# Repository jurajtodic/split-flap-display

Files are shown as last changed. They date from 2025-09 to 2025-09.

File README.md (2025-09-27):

# ESP32 WiFi Controlled Split-Flap Display

This repository contains the complete technical documentation, 3D models, and firmware for a fully functional, 8-module electromechanical split-flap display. The entire system is controlled over Wi-Fi via a web interface hosted directly on the ESP32 microcontroller.

### Watch the Display in Action!

Below are silent previews of the display's two primary modes. The iconic sound is a key feature, so click the title links to see and hear the full videos.

---

### [**Word Mode Demo (Click for Video with Sound)**](https://github.com/jurajtodic/split-flap-display/raw/main/assets/word_mode_test.mp4)

*Displaying a custom message sent from the web interface. The video shows the recalibration process followed by the display of the word "HELLO WORLD".*

Demonstration of the Split-Flap Display in Word Mode

---

### [**Clock Mode Demo (Click for Video with Sound)**](https://github.com/jurajtodic/split-flap-display/raw/main/assets/clock_mode_test.mp4)

*The display functioning as an internet-synchronized clock, updating every second to show the time in HH:MM:SS format.*

Demonstration of the Split-Flap Display in Clock Mode

---

## Project Overview

Inspired by the classic departure boards found in train stations and airports, this project recreates the iconic and satisfying "clatter" of a split-flap display in a compact, modern, and open-source package. The display has a dual-mode functionality: it can operate as a web-controlled message board or as an accurate, internet-synchronized clock.

The core engineering challenge was to create a reliable and precise positioning system for eight independent stepper motors without accumulating errors over time. This was solved using a closed-loop feedback mechanism with Hall effect sensors, all managed by a non-blocking state machine architecture in the firmware.

## Key Features

*   **8 Independent Modules:** An 8-character display capable of showing the full alphabet, numbers, and symbols.
*   **Wi-Fi Control:** Features a built-in web server hosted on the ESP32, allowing you to change messages and modes from any device on the network.
*   **Dual Mode Functionality:**
    *   **Word Mode:** Display any custom message up to 8 characters long.
    *   **Clock Mode:** Automatically fetches the current time from an NTP server and displays it in HH:MM:SS format.
*   **Auto-Calibration & Error Correction:** Each module uses a magnet and a Hall effect sensor to find a "home" position, preventing cumulative errors. The firmware also features an on-the-fly error correction mechanism that passively corrects for missed steps during operation.
*   **Non-Blocking Code:** The firmware is built on a state-machine model, allowing it to manage motor movements, serve the web page, and listen for commands simultaneously without delays.
*   **Fully Open Source:** All hardware schematics, 3D printable models, and source code are available here.

## How It Works

The system is a blend of mechanical design, custom electronics, and advanced firmware.

### Mechanical Design

The display is modular, with each of the eight character units being identical. The housing, rotor, and flaps were modeled in Tinkercad and are designed to be 3D printed. Precision is key to ensure the 36 flaps on each rotor can move freely without jamming.

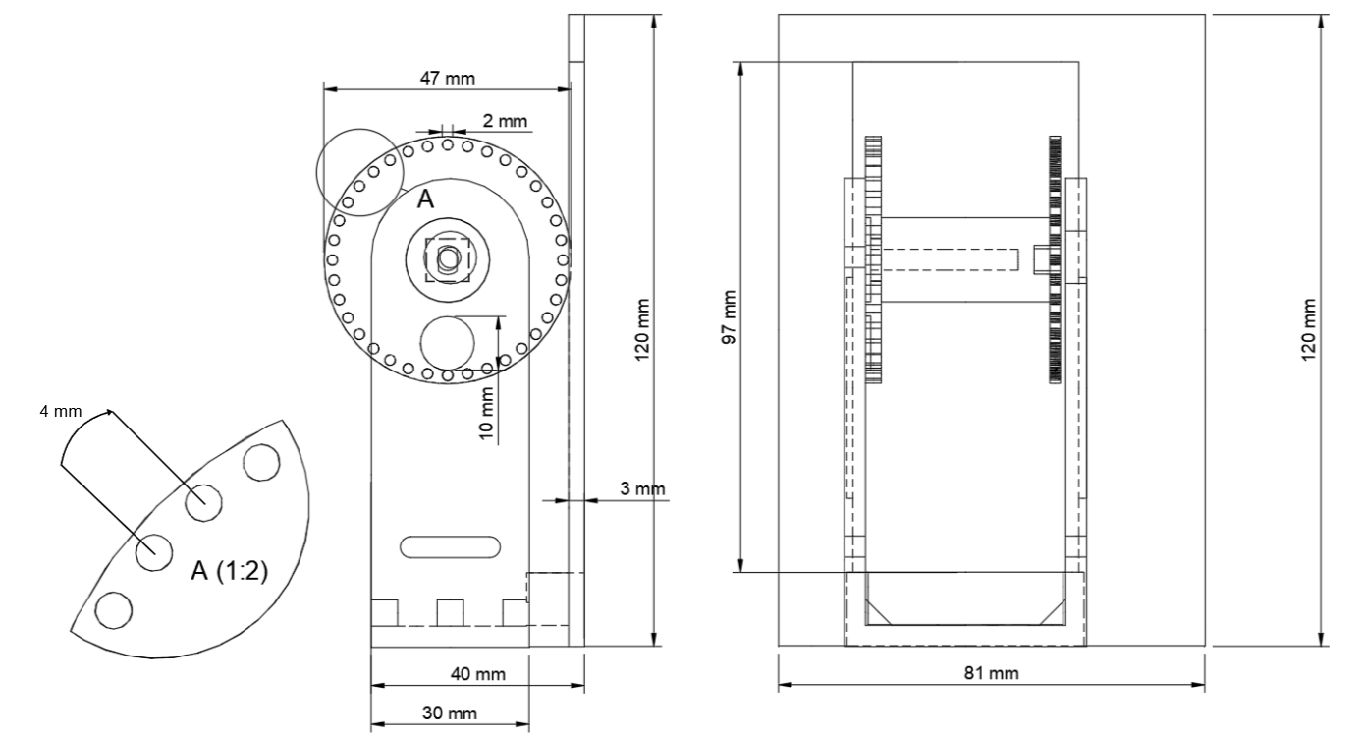
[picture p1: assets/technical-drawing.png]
Technical Drawing of a Single Module


### Electronics and Wiring

An ESP32-DevKitC serves as the brain of the project. Since the ESP32 lacks enough GPIO pins to directly control all eight stepper motors (requiring 32 lines), four **74HC595 shift registers** are used to expand the outputs. This allows all 32 motor control lines to be managed using just three ESP32 pins (DATA, CLOCK, LATCH).

Each module's feedback loop consists of a small neodymium magnet embedded in the rotor and an **A3144 Hall effect sensor** mounted to the frame. When the magnet passes the sensor, a signal is sent to the ESP32, marking a precise reference point.

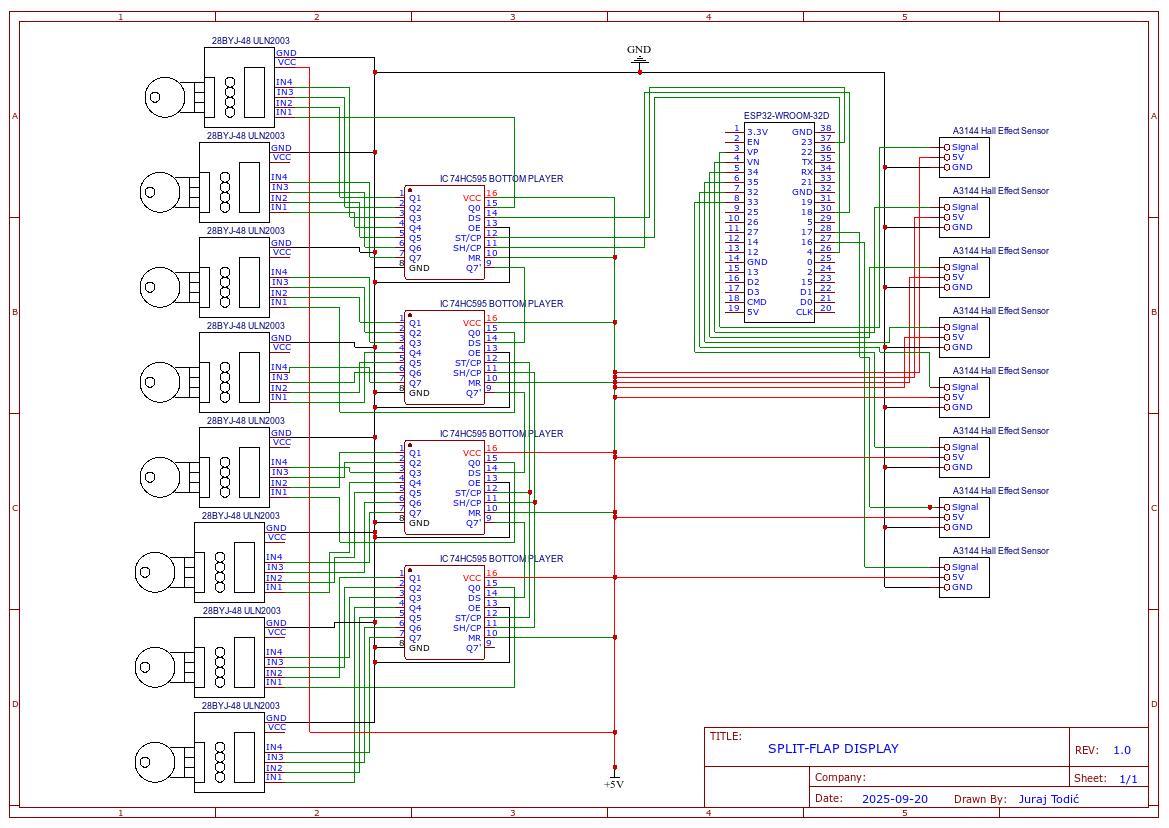
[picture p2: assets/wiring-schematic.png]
Complete Wiring Schematic


### Software Breakdown

The firmware is developed in C++ using the PlatformIO IDE. The core logic is a **non-blocking state machine**. Instead of using `delay()` functions that would halt the processor, the main `loop()` runs thousands of times per second. In each cycle, it:
1.  Checks for incoming web clients.
2.  Updates the state of each of the eight motors (e.g., `IDLE`, `MOVING_TO_TARGET`, `RECALIBRATING`).
3.  Calculates the necessary motor steps based on trapezoidal speed profiles for smooth acceleration and deceleration.
4.  Sends the updated motor states as a single 32-bit pattern to the shift registers.

This approach ensures the device is always responsive to web commands, even while the motors are in motion.

## Getting Started

To build your own split-flap display, follow these steps.

### Prerequisites

*   All the hardware components listed in the technical report.
*   A 3D printer to create the mechanical parts.
*   Visual Studio Code with the **PlatformIO IDE** extension installed.

### Setup and Upload

1.  **Clone the repository:**
    ```sh
    git clone https://github.com/your-username/your-repo-name.git
    ```
2.  **Open the project** in Visual Studio Code. It should be automatically recognized as a PlatformIO project.
3.  **Configure Wi-Fi:** Open the `src/main.cpp` file and update the following lines with your network credentials:
    ```cpp
    const char* ssid = "YOUR_WIFI_SSID";
    const char* password = "YOUR_WIFI_PASSWORD";
    ```
4.  **Build and Upload:** Connect your ESP32 board to your computer and click the "Upload" button in the PlatformIO toolbar at the bottom of VS Code.
5.  **Find the IP Address:** After uploading, open the Serial Monitor. The ESP32 will print its IP address once it connects to your network.

### How to Use

1.  Open a web browser on any device connected to the same Wi-Fi network.
2.  Navigate to the IP address you found in the previous step.
3.  Use the web interface to switch between Word and Clock mode, or to enter a new message to display!

## Known Issues & Future Improvements

This prototype is fully functional but, as a first iteration, has clear areas for enhancement to improve its long-term reliability and ease of assembly.

*   **Firmware Edge Cases:** The state-driven, non-blocking firmware is highly efficient but can occasionally exhibit unpredictable behavior in rare edge cases (e.g., a web request arriving at the exact moment a motor state changes). If a module behaves erratically or gets stuck unexpectedly, a software fix should be considered. Investigating and reinforcing the state machine logic in the firmware should be the first step in debugging.
*   **Mechanical Tolerances:** The 3D printed parts have inherent tolerances that can lead to minor misalignments, which is the primary source of occasional display errors. A design with tighter tolerances would improve performance.
*   **Sensor Placement:** The manual placement of the Hall effect sensors is critical and highly sensitive. A revised 3D model with a fixed, non-adjustable mounting point for the sensors would greatly improve reliability and simplify the calibration process.

## Inspiration and Credits

This project was heavily inspired by the work of other makers in the open-source community.

A special thanks goes to **Scott Bezek** for his incredible [splitflap project](https://github.com/scottbez1/splitflap), which served as a foundational resource.

Additionally, I would like to credit **AudasWasTaken**. The 3D models in this project were originally based on the files from their [Split-Flap_Display repository](https://github.com/AudasWasTaken/Split-Flap_Display) and were then modified to fit the specific components and mechanics of this design.

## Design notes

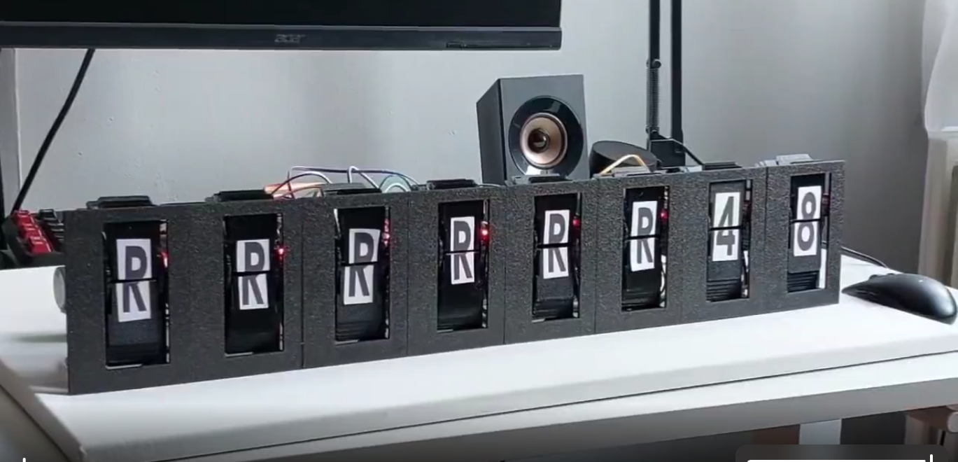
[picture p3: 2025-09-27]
assets/thumbnail.png

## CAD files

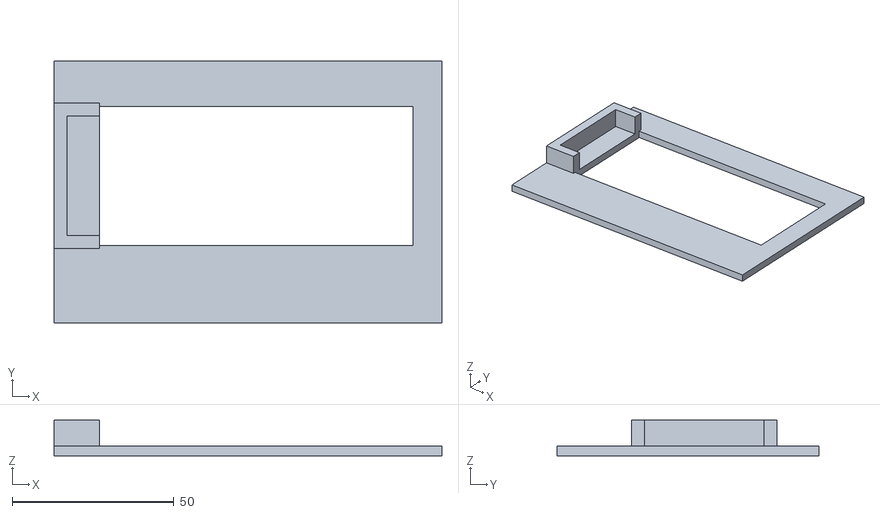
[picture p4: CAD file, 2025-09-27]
3d_model/spool_cover.stl
120.0 x 81.0 x 11.0

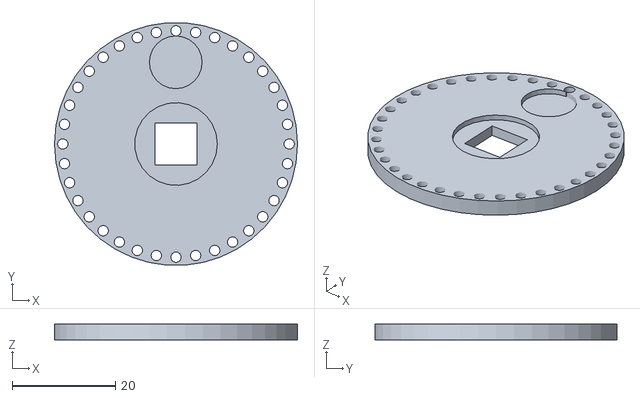
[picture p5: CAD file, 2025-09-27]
3d_model/split-flap_spool_top.stl
47.0 x 46.9 x 3.00

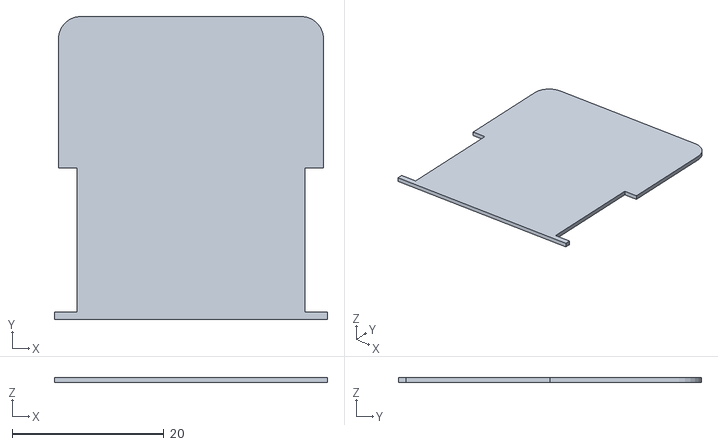
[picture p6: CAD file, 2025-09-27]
3d_model/split-flap_flap.stl
36.0 x 40.0 x 0.7

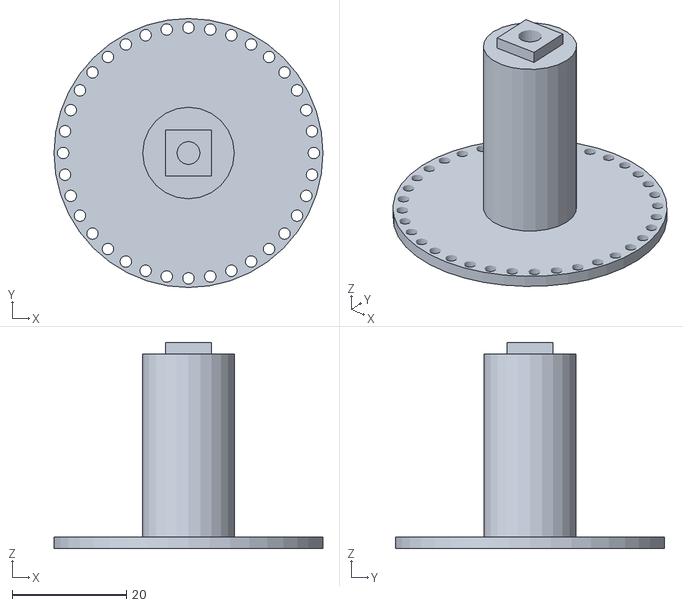
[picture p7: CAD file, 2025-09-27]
3d_model/split-flap_spool_bot.stl
47.0 x 47.0 x 36.0

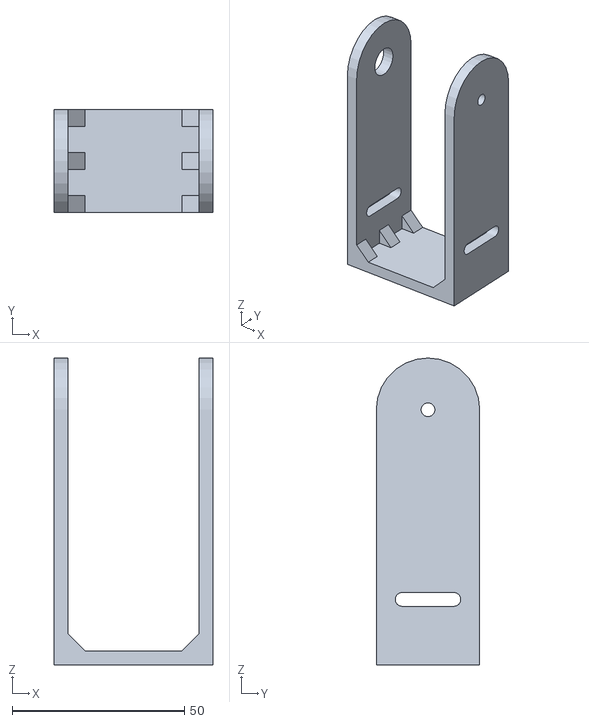
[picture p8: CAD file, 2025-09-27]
3d_model/split-flap_case.stl
46.0 x 30.0 x 89.0

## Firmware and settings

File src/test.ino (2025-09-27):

#include <Arduino.h>
#include <SPI.h>
#include <WiFi.h>
#include <NTPClient.h>
#include <WiFiUdp.h>

// --- Wi-Fi & Time Configuration ---
const char* ssid = "JurajevMob";
const char* password = "juki1234";
WiFiServer server(80);
WiFiUDP ntpUDP;
NTPClient timeClient(ntpUDP, "pool.ntp.org", 7200); 
int lastDisplayedSecond = -1;

// --- System Configuration ---
const int NUM_STEPPERS = 8;
const int NUM_SHIFT_REGISTERS = 4;
const int DATA_PIN = 23;
const int CLOCK_PIN = 18;
const int LATCH_PIN = 4;

// --- Stepper Motor & Flap Properties ---
const int STEPS_PER_REVOLUTION = 2048;
const int NUM_FLAPS = 36;
const long BASE_STEPS_PER_FLAP = STEPS_PER_REVOLUTION / NUM_FLAPS;

// --- Behavior Configuration ---
const int MOVES_FOR_RECALIBRATION_WORD_MODE = 2;
const int NUDGE_STEPS = 35;
const long RECALIBRATION_TIMEOUT_STEPS = STEPS_PER_REVOLUTION * 2;
const int BLIND_SPIN_STEPS = 300; 

// --- Speed & Ramping Configuration ---
const int MAX_SPEED_DELAY_US = 2200;
const int START_STOP_DELAY_US = 2200;
const int RECALIBRATE_DELAY_US = 2200;
const int RAMP_STEPS = 300;

// --- Character Mapping ---
const char letterMap[] = {
    'R', 'S', 'T', 'U', 'V', 'W', 'X', 'Y', 'Z', '9', '8', '7',
    '6', '5', '4', '3', '2', '1', '0', 'A', 'B', 'C', 'D', 'E',
    'F', 'G', 'H', 'I', 'J', 'K', 'L', 'M', 'N', ':', 'P', 'Q'
};
const char tensDigitMap[] = {
    '4', '5', '0', '1', '2', '3', '4', '5', '0', '1', '2', '3',
    '4', '5', '0', '1', '2', '3', '4', '5', '0', '1', '2', '3',
    '4', '5', '0', '1', '2', '3', '4', '5', '0', '1', '2', '3'
};
const char unitsDigitMap[] = {
    '8', '9', '0', '1', '2', '3', '4', '5', '6', '7',
    '8', '9', '0', '1', '2', '3', '4', '5', '6', '7',
    '8', '9', '0', '1', '2', '3', '4', '5', '6', '7',
    '8', '9', '0', '1', '2', '3'
};

// --- Low-Level Control ---
const byte step_patterns[] = {0b1001, 0b1100, 0b0110, 0b0011};
byte output_buffer[NUM_SHIFT_REGISTERS];

// --- System State Machine ---
enum DisplayMode { WORD_MODE, CLOCK_MODE };
DisplayMode currentMode = WORD_MODE;

enum MotorActivity {
    IDLE, RECALIBRATING_START, RECALIBRATING_BLIND_SPIN, RECALIBRATING_FIND_HOME, RECALIBRATING_FIND_EDGE,
    MOVING_TO_TARGET, NUDGING_FORWARD, NUDGING_BACKWARD, HALTED
};

struct MotorState {
    const int hall_pin;
    MotorActivity state = RECALIBRATING_START;
    long current_pos = 0;
    long target_pos = 0;
    int phase = 0;
    unsigned long last_step_time_us = 0;
    int current_step_delay_us = START_STOP_DELAY_US;
    long steps_in_current_move = 0;
    long total_steps_for_move = 0;
    int nudge_step_counter = 0;
    int moves_since_recalibration = 0; // Only for WORD_MODE
    char post_recal_target_char = '\0';
    long recalibration_step_counter = 0;

    // --- "LAP TIMER" VARIABLES ---
    long steps_since_last_home = 0;
    long position_error = 0;
    // This flag is our "memory" of the sensor's previous state to detect a fresh trigger.
    bool home_sensor_active = false; 

    MotorState(int pin) : hall_pin(pin) {}
};

MotorState motors[NUM_STEPPERS] = {
  {36}, {39}, {34}, {35}, {32}, {33}, {17}, {16}
};

void setTargetWord(String word);

// --- Core Functions ---
void updateShiftRegisters(bool releaseTorque) {
    if (releaseTorque) { memset(output_buffer, 0, sizeof(output_buffer)); }
    digitalWrite(LATCH_PIN, LOW);
    for (int i = NUM_SHIFT_REGISTERS - 1; i >= 0; i--) { SPI.transfer(output_buffer[i]); }
    digitalWrite(LATCH_PIN, HIGH);
}

void stepMotor(int motorIndex, bool forward) {
    motors[motorIndex].phase = (motors[motorIndex].phase + (forward ? -1 : 1) + 4) % 4;
    motors[motorIndex].current_pos += (forward ? 1 : -1);
    byte pattern = step_patterns[motors[motorIndex].phase];
    int start_bit_pos = motorIndex * 4;
    int start_byte_index = start_bit_pos / 8;
    int bit_shift_in_byte = start_bit_pos % 8;
    
    output_buffer[start_byte_index] &= ~(0b1111 << bit_shift_in_byte);
    if (bit_shift_in_byte > 4 && start_byte_index + 1 < NUM_SHIFT_REGISTERS) {
         output_buffer[start_byte_index + 1] &= ~(0b1111 >> (8-bit_shift_in_byte));
    }
    output_buffer[start_byte_index] |= (pattern << bit_shift_in_byte);
    if (bit_shift_in_byte > 4 && start_byte_index + 1 < NUM_SHIFT_REGISTERS) {
        output_buffer[start_byte_index + 1] |= (pattern >> (8 - bit_shift_in_byte));
    }

    // --- "LAP TIMER" LOGIC ---
    motors[motorIndex].steps_since_last_home++;
    
    // Check the sensor's state RIGHT NOW. (LOW means active)
    bool is_active = (digitalRead(motors[motorIndex].hall_pin) == LOW);
    
    // Check for the LEADING EDGE: Was the sensor OFF before, but is ON now?
    if (is_active && !motors[motorIndex].home_sensor_active) {
        // Lap complete! Calculate the error from the ideal revolution size.
        motors[motorIndex].position_error = motors[motorIndex].steps_since_last_home - STEPS_PER_REVOLUTION;
        Serial.printf("Motor %d: LAP! %ld steps. Error: %ld\n", motorIndex, motors[motorIndex].steps_since_last_home, motors[motorIndex].position_error);
        
        // Reset the lap counter for the next revolution.
        motors[motorIndex].steps_since_last_home = 0;
    }
    
    // Update the "memory" for the next step's comparison.
    motors[motorIndex].home_sensor_active = is_active;
}

// --- Main Action Functions ---
void setTargetWord(String word) {
    for (int i = 0; i < NUM_STEPPERS; i++) {
        if (motors[i].state == RECALIBRATING_BLIND_SPIN || motors[i].state == RECALIBRATING_FIND_HOME || motors[i].state == RECALIBRATING_FIND_EDGE) {
            continue;
        }
        if (motors[i].state == HALTED) continue;

        if (motors[i].position_error != 0) {
            motors[i].current_pos -= motors[i].position_error; // Apply correction
            Serial.printf("Motor %d: Applying correction of %ld steps.\n", i, -motors[i].position_error);
            motors[i].position_error = 0; // Clear error after use
        }

        char targetLetter = (i < word.length()) ? toupper(word[i]) : ' ';
        if (targetLetter == 'O') targetLetter = '0';

        long current_flap_pos = (motors[i].current_pos % STEPS_PER_REVOLUTION) / BASE_STEPS_PER_FLAP;
        long flaps_to_move = 0;
        int targetIndex = -1;

        if (currentMode == WORD_MODE) {
            if (i >= 6) targetLetter = ' ';

            for (int j = 0; j < NUM_FLAPS; j++) { if (letterMap[j] == targetLetter) { targetIndex = j; break; } }
            if (targetIndex == -1) continue;

            motors[i].moves_since_recalibration++;
            if (motors[i].moves_since_recalibration >= MOVES_FOR_RECALIBRATION_WORD_MODE) {
                motors[i].post_recal_target_char = targetLetter;
                motors[i].state = RECALIBRATING_START;
                continue;
            }
            flaps_to_move = (targetIndex - current_flap_pos + NUM_FLAPS) % NUM_FLAPS;
        } else { // CLOCK_MODE
            const char* currentMap;
            int numUniqueFlaps;

            if (i < 6) { currentMap = letterMap; numUniqueFlaps = NUM_FLAPS; }
            else if (i == 6) { currentMap = tensDigitMap; numUniqueFlaps = 6; }
            else { currentMap = unitsDigitMap; numUniqueFlaps = 10; }

            for (int j = 0; j < NUM_FLAPS; j++) { if (currentMap[j] == targetLetter) { targetIndex = j; break; } }
            if (targetIndex == -1) continue;
            
            if (i < 6) {
                 flaps_to_move = (targetIndex - current_flap_pos + NUM_FLAPS) % NUM_FLAPS;
            } else {
                long current_flap_unique_pos = current_flap_pos % numUniqueFlaps;
                long target_flap_unique_pos = targetIndex % numUniqueFlaps;
                flaps_to_move = (target_flap_unique_pos - current_flap_unique_pos + numUniqueFlaps) % numUniqueFlaps;

                if (flaps_to_move == 0 && i == 7) { 
                    flaps_to_move = numUniqueFlaps; 
                }
            }
        }

        if (flaps_to_move > 0) {
            long steps_to_move = flaps_to_move * BASE_STEPS_PER_FLAP;
            motors[i].target_pos = motors[i].current_pos + steps_to_move;
            motors[i].total_steps_for_move = steps_to_move;
            motors[i].steps_in_current_move = 0;
            motors[i].state = MOVING_TO_TARGET;
        } else {
            motors[i].state = IDLE;
        }
    }
}

void recalibrateAllMotors() {
    Serial.println("Web request received: Recalibrating all motors.");
    for (int i = 0; i < NUM_STEPPERS; i++) {
        if (motors[i].state != HALTED) {
            motors[i].post_recal_target_char = '\0';
            motors[i].state = RECALIBRATING_START;
        }
    }
}

// --- State Machine ---
void updateMotor(int motorIndex) {
    MotorState &motor = motors[motorIndex];
    if (motor.state == IDLE || motor.state == HALTED) { return; }
    if (micros() - motor.last_step_time_us < motor.current_step_delay_us) { return; }
    motor.last_step_time_us = micros();

    switch (motor.state) {
        case RECALIBRATING_START:
            motor.current_step_delay_us = RECALIBRATE_DELAY_US;
            motor.recalibration_step_counter = 0;
            motor.state = RECALIBRATING_BLIND_SPIN;
            break;

        case RECALIBRATING_BLIND_SPIN:
            if (motor.recalibration_step_counter >= BLIND_SPIN_STEPS) {
                motor.recalibration_step_counter = 0;
                motor.state = RECALIBRATING_FIND_HOME;
                break;
            }
            stepMotor(motorIndex, true);
            motor.recalibration_step_counter++;
            break;

        case RECALIBRATING_FIND_HOME:
            stepMotor(motorIndex, true); motor.recalibration_step_counter++;
            if (digitalRead(motor.hall_pin) == HIGH) {
                motor.state = RECALIBRATING_FIND_EDGE;
            }
            if (motor.recalibration_step_counter > RECALIBRATION_TIMEOUT_STEPS) {
                motor.state = HALTED;
            }
            break;

        case RECALIBRATING_FIND_EDGE:
            stepMotor(motorIndex, true);
            motor.recalibration_step_counter++;
            if (digitalRead(motor.hall_pin) == LOW) {
                motor.current_pos = 0; motor.target_pos = 0;
                motor.moves_since_recalibration = 0;

                // After recalibrating, reset the lap timer too for a clean start.
                motors[motorIndex].steps_since_last_home = 0;
                motors[motorIndex].position_error = 0;
                motors[motorIndex].home_sensor_active = true; // Sensor is active now

                if (motor.post_recal_target_char != '\0') {
                    char tempTarget = motor.post_recal_target_char;
                    motor.post_recal_target_char = '\0';
                    String word_to_set = "";
                    for(int i=0; i<NUM_STEPPERS; i++) { word_to_set += (i==motorIndex) ? tempTarget : ' '; }
                    setTargetWord(word_to_set);
                } else {
                    motor.state = IDLE;
                }
            }
            if (motor.recalibration_step_counter > RECALIBRATION_TIMEOUT_STEPS) {
                 motor.state = HALTED;
            }
            break;
            
        case MOVING_TO_TARGET:
            if (motor.current_pos >= motor.target_pos) {
                motor.nudge_step_counter = 0; motor.state = NUDGING_FORWARD; break;
            }
            if (motor.steps_in_current_move < RAMP_STEPS) {
                motor.current_step_delay_us = START_STOP_DELAY_US - ((START_STOP_DELAY_US - MAX_SPEED_DELAY_US) * motor.steps_in_current_move / RAMP_STEPS);
            } else if (motor.steps_in_current_move >= (motor.total_steps_for_move - RAMP_STEPS)) {
                long decel_step = motor.steps_in_current_move - (motor.total_steps_for_move - RAMP_STEPS);
                motor.current_step_delay_us = MAX_SPEED_DELAY_US + ((START_STOP_DELAY_US - MAX_SPEED_DELAY_US) * decel_step / RAMP_STEPS);
            } else { motor.current_step_delay_us = MAX_SPEED_DELAY_US; }
            stepMotor(motorIndex, true); motor.steps_in_current_move++;
            break;
        case NUDGING_FORWARD:
            motor.current_step_delay_us = START_STOP_DELAY_US;
            if (motor.nudge_step_counter >= NUDGE_STEPS) {
                motor.nudge_step_counter = 0; motor.state = NUDGING_BACKWARD; break;
            }
            stepMotor(motorIndex, true); motor.nudge_step_counter++;
            break;
        case NUDGING_BACKWARD:
            motor.current_step_delay_us = START_STOP_DELAY_US;
            if (motor.nudge_step_counter >= NUDGE_STEPS) {
                motor.state = IDLE; break;
            }
            stepMotor(motorIndex, false); motor.nudge_step_counter++;
            break;
    }
}

// --- Wi-Fi & Mode Functions ---
void setupWiFi() {
  Serial.print("Connecting to "); Serial.println(ssid);
  WiFi.begin(ssid, password);
  while (WiFi.status() != WL_CONNECTED) {
    delay(500); Serial.print(".");
  }
  Serial.println("\nWiFi connected!");
  Serial.print("IP Address: "); Serial.println(WiFi.localIP());
  server.begin();
  timeClient.begin();
  timeClient.update();
  Serial.println("Web server and NTP client started.");
}

void handleClient() {
  WiFiClient client = server.available();
  if (!client) { return; }

  String request = client.readStringUntil('\r');
  client.flush();

  if (request.indexOf("GET /recalibrate") != -1) {
    recalibrateAllMotors();
  } else if (request.indexOf("GET /set_clock_mode") != -1) {
    currentMode = CLOCK_MODE;
    timeClient.update();
    lastDisplayedSecond = -1; 
  } else if (request.indexOf("GET /set_word_mode") != -1) {
    currentMode = WORD_MODE;
  } else if (request.indexOf("/move?word=") != -1) {
    int startIndex = request.indexOf('=') + 1;
    int endIndex = request.indexOf(' ', startIndex);
    String targetWord = request.substring(startIndex, endIndex);
    targetWord.replace("%20", " ");
    setTargetWord(targetWord);
  }
  
  client.println("HTTP/1.1 200 OK");
  client.println("Content-type:text/html");
  client.println();
  client.println("<html><head><title>Split-Flap Control</title><style>body{font-family: sans-serif; text-align: center;} form,div{margin-bottom: 20px;}</style></head><body><h1>Split-Flap Control</h1>");
  
  if (currentMode == WORD_MODE) {
    client.println("<div>Current Mode: <b>Word Display</b></div>");
    client.printf("<form action='/move' method='GET'>");
    // Updated to 6 characters
    client.printf("Enter up to 6 characters: <input type='text' name='word' maxlength='6' style='padding: 5px; text-transform: uppercase;'><br><br>");
    client.println("<input type='submit' value='Display Word' style='padding: 10px;'>");
    client.println("</form>");
    client.println("<form action='/set_clock_mode' method='GET'><input type='submit' value='Switch to Clock Mode' style='padding: 10px;'></form>");
  } else { // CLOCK_MODE
    client.println("<div>Current Mode: <b>Clock</b></div>");
    // Updated to show full time, including note about UTC
    client.printf("<div>Current Time (UTC): %s</div>", timeClient.getFormattedTime().c_str());
    client.println("<form action='/set_word_mode' method='GET'><input type='submit' value='Switch to Word Mode' style='padding: 10px;'></form>");
  }
  
  client.println("<hr style='margin-top: 30px;'>");
  client.println("<form action='/recalibrate' method='GET'>");
  client.println("<input type='submit' value='Recalibrate All Motors' style='padding: 10px; background-color: #f44336; color: white; border: none; margin-top: 10px;'>");
  client.println("</form>");
  client.println("</body></html>");
  delay(1);
  client.stop();
}

void loopWordMode() { /* Word mode is entirely driven by web commands */ }

void loopClockMode() {
    timeClient.update();
    int currentSecond = timeClient.getSeconds();
    if (currentSecond != lastDisplayedSecond) {
        lastDisplayedSecond = currentSecond;
        char timeString[9]; 
        sprintf(timeString, "%02d:%02d:%02d", timeClient.getHours(), timeClient.getMinutes(), timeClient.getSeconds());
        setTargetWord(String(timeString));
    }
}

// --- Main Program ---
void setup() {
    Serial.begin(115200);
    Serial.println("--- Dual Mode Split-Flap Display ---");
    
    // First, connect to WiFi
    setupWiFi();
    
    // Second, initialize pins and SPI
    pinMode(LATCH_PIN, OUTPUT);
    digitalWrite(LATCH_PIN, HIGH);
    for (int i = 0; i < NUM_STEPPERS; i++) {
        pinMode(motors[i].hall_pin, INPUT_PULLUP);
    }
    SPI.begin();
    SPI.setFrequency(4000000);
    
    // Force time synchronization BEFORE calibrating
    Serial.print("Waiting for first NTP time sync...");
    // The getEpochTime() will be very low (near 0) until the first sync has completed.
    // An Epoch time less than 1 billion is a reliable way to check if it's a real, modern time.
    while (timeClient.getEpochTime() < 1000000000) {
      timeClient.update();
      Serial.print(".");
      delay(1000);
    }
    Serial.println("\nTime has been synchronized!");

    // Finally, now that we have the correct time, recalibrate all motors
    // This will run AFTER the initial RECALIBRATING_START state is set in the MotorState struct.
    recalibrateAllMotors();
}

void loop() {
    handleClient(); // Make sure your full handleClient function is here
    if (currentMode == WORD_MODE) {
        loopWordMode();
    } else {
        loopClockMode();
    }
    
    bool any_motor_is_moving = false;
    memset(output_buffer, 0, sizeof(output_buffer));
    for (int i = 0; i < NUM_STEPPERS; i++) {
        updateMotor(i);
        if (motors[i].state != IDLE && motors[i].state != HALTED) {
            any_motor_is_moving = true;
            byte pattern = step_patterns[motors[i].phase];
            int start_bit_pos = i * 4;
            int start_byte_index = start_bit_pos / 8;
            int bit_shift_in_byte = start_bit_pos % 8;

            output_buffer[start_byte_index] |= (pattern << bit_shift_in_byte);
            if (bit_shift_in_byte > 4 && start_byte_index + 1 < NUM_SHIFT_REGISTERS) {
                output_buffer[start_byte_index + 1] |= (pattern >> (8 - bit_shift_in_byte));
            }
        }
    }
    if (any_motor_is_moving) {
        updateShiftRegisters(false);
    } else {
        updateShiftRegisters(true);
        delay(20);
    }
}
